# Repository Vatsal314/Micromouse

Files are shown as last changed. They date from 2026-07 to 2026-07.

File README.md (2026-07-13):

# MicroMouse: Autonomous Maze-Solving Robot

An autonomous, self-navigating maze-solving robot designed to map, compute, and solve a grid using the Flood Fill algorithm. The system features a custom-designed PCB to streamline power and sensing, coupled with real-time sensor feedback over standard serial protocols.  

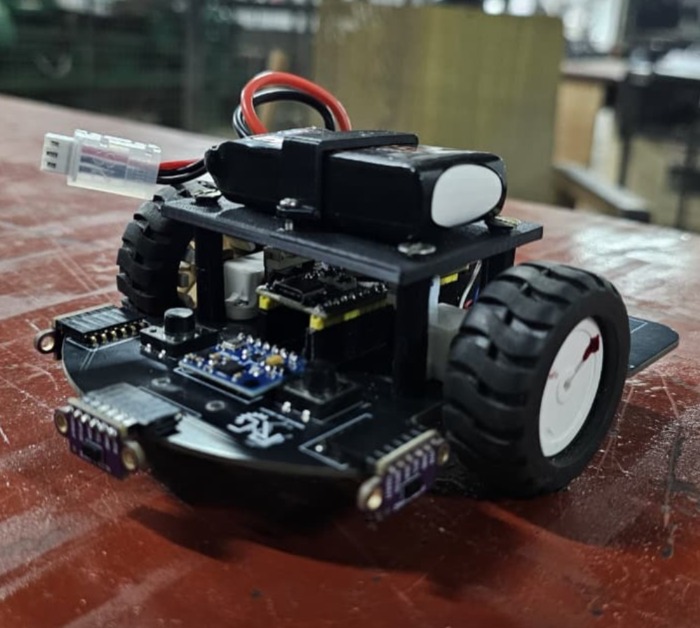
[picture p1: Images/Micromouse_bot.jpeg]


## Tech Stack & Hardware Components
- Microcontroller: STM32F411CEU6 "Black Pill" (ARM Cortex-M4)
- Core Algorithm: Flood Fill (Maze mapping, cell weight updates, and path optimization)
- Sensing & Telemetry: 
  - VL53L0X Time-of-Flight (ToF) sensors for precise distance/wall detection
  - MPU6050 Gyroscope/Accelerometer for straight-line stabilization and precise turns
- Actuation & Control: 
  - 12V 1000RPM N20 Encoder Motors for closed-loop speed control
  - TB6612FNG Dual Motor Driver
- Power Management: 11.1V LiPo battery pack with onboard regulation for logic and motor rails
- Design Tools: KiCad (Schematics & PCB Layout)

## Firmware & Logic Implementation
- Maze Solving: Implements a dynamic Flood Fill matrix routine that updates cell values on the fly as the mouse discovers walls.
- Hardware Integration: Configured SPI/I2C buses to communicate with peripheral sensors and motor drivers, ensuring low-latency feedback loops for precise alignment.

## Hardware Architecture & PCB Design
To minimize structural footprint and eliminate complex wiring failure points, a custom multi-layer PCB was fabricated.
- Power Management: Dedicated onboard regulation filtering out 12V motor noise from the sensitive 3.3V STM32 logic lines.
- Sensor Alignment: Precise angled placement for the VL53L0X ToF sensors to map front and side clearances accurately.

## Maze Description
The robot was tested and validated in a physical maze environment configured with the following specifications:
- Dimensions and Grid: A modular grid layout featuring distinct pathways, vertical wall dividers, and an enclosed central target zone.
- Physical Construction: Built using white foam board panels for the structural walls and a gridded base layer featuring blue alignment markings to delineate cell thresholds.
- Core Objective: The robot starts from the outer perimeter and relies on real-time sensory feedback to dynamically map cell paths, track orientation changes, and navigate toward the centralized goal area.

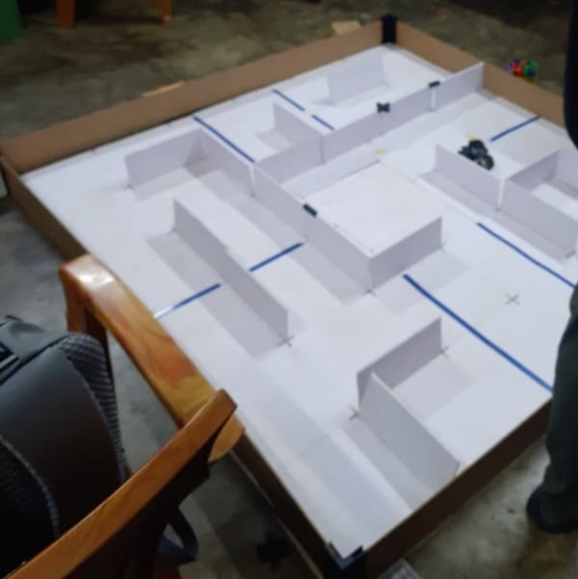
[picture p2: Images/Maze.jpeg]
- 

## Algorithm & Firmware Implementation

The robot utilizes a dynamic Flood Fill algorithm optimized for real-time maze-mapping, tracking orientation updates, path optimization, and execute routines.

### 1. Maze Initialization (Flood Fill Array)
- **Manhattan Distance Matrix:** At startup, the `initFloodfill` routine populates the `arena_map` grid using Manhattan distance bounds calculated relative to the target cell coordinate `(0, length - 1)`. Every cell is given an initial cost matrix weight indicating its theoretical steps away from the destination.
- **Perimeter Boundary Flagging:** The `initWalls` function instantiates the initial maze boundary configuration, defaulting the grid's outer boundary elements to closed parameters.

### 2. Sensor Polling & Real-Time Mapping
- **Dynamic Wall Updating:** During runtime execution loop, the robot polls data from the left, right, and center VL53L0X Time-of-Flight (ToF) sensors. If an obstacle distance drops below `detectDist` (180 mm), the corresponding coordinate index within the global `wall_data` matrix is permanently flagged (`= 1`).
- **Orientation-Aware Bitmasking:** The code tracks the absolute heading (`facing` variable mapping to 0: West, 1: North, 2: East, 3: South). Relative ToF configurations (Left, Front, Right) are translated into absolute compass coordinates to ensure accurate wall updates as the orientation shifts.

### 3. Queue-Driven Map Restructuring (`rearrange_map`)
- **Dead-End Discovery:** If the robot discovers new walls that make its current cell value equal to or lower than all accessible adjacent neighbors, the `rearrange_map` routine initiates.
- **BFS Flood Refresh:** The cell coordinate is pushed onto a custom `Queue` structure. The program continuously pops elements from the queue, calculating the minimum accessible neighbor via `minimum_value_accessible_neighbors`. The cell value is updated dynamically to `smallest_neighbor_value + 1`, and all unblocked adjacent neighbors are placed into the queue to recursively refresh the local routing map.

### 4. Navigation & Path Optimization
- **Compass to Action Translation:** The system determines optimal cell transitions through the `direction_wrt_bot` routine. It converts required compass steps into actual motion commands (`moveForward`, `TurnLeft`, `TurnRight`, `Turn180`).
- **Stack-Based Path Reduction:** As the mouse explores the maze, it tracks steps sequentially inside `path_taken`. Dead ends or backtracks are parsed by `reduceDirections`, which processes the path string through a custom stack interface to discard inverse direction pairings (e.g., North-South or East-West cancellations). This converts the discovery track into a clean tracking coordinate sequence saved into `short_path`.

### 5. Acceleration-Optimized Final Run (`final_run`)
- After mapping out the optimal trajectory, the system executes a localized final straightaway acceleration routine via `final_run`. 
- Instead of stopping at every single node intersection, the algorithm aggregates sequential straight moves (`steps++`). If sequential cells follow a uniform direction, it executes long-distance acceleration (`moveForward(steps * steplength * 0.9)`) coupled with tuned PD constants (`KP_WALL`, `KD_WALL`, `KP_YAW`), leveraging the N20 encoders for high-speed transit.

## Hardware Design & PCB Layout

### Schematic Capture
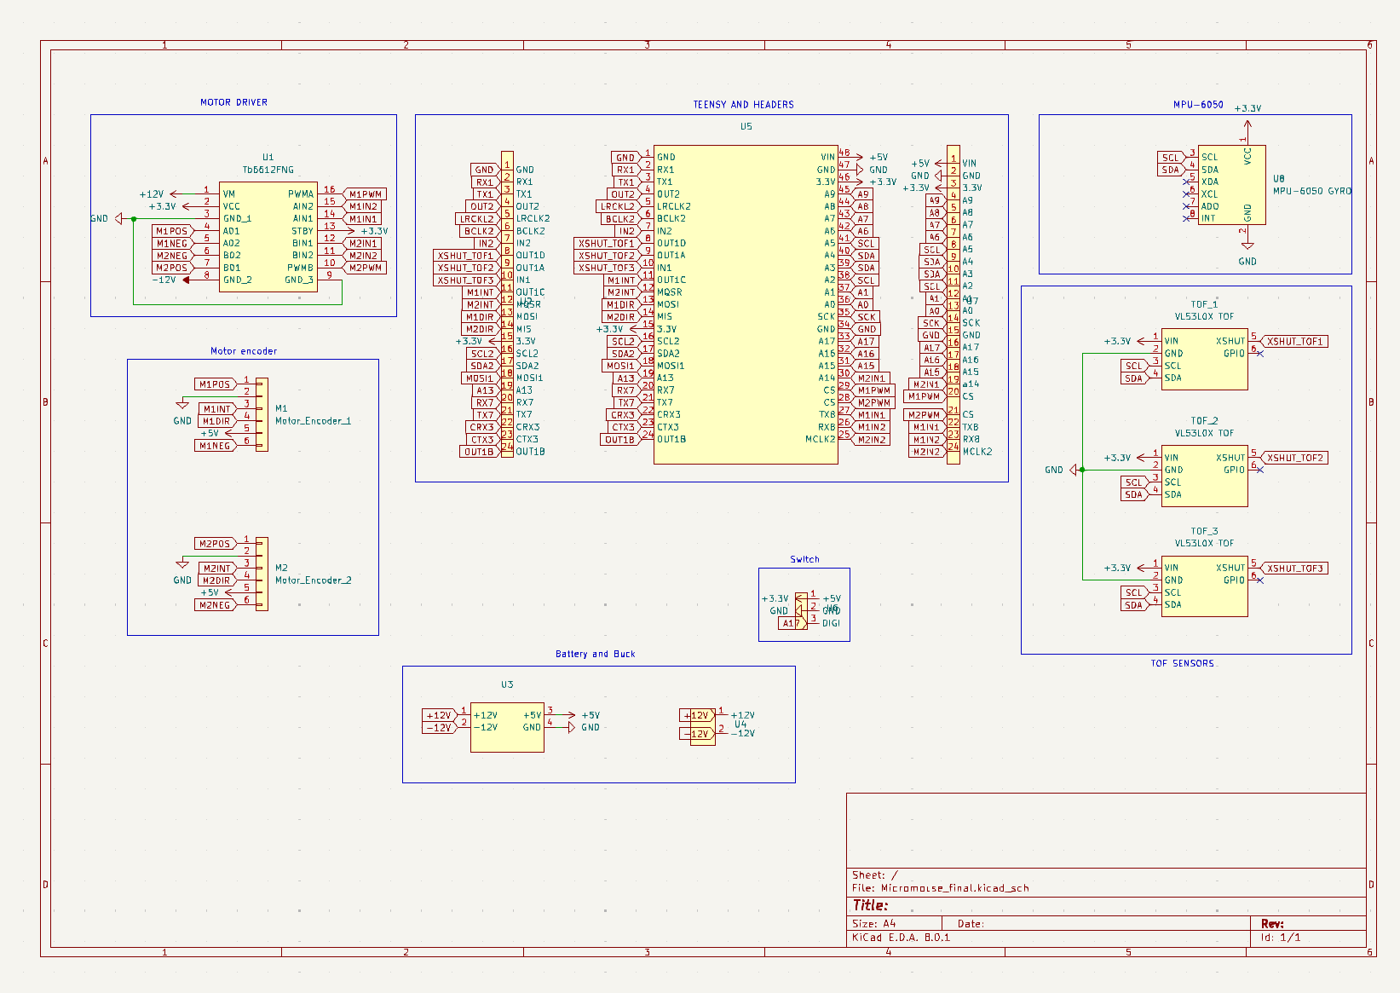
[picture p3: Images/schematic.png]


### PCB Layout & Routing
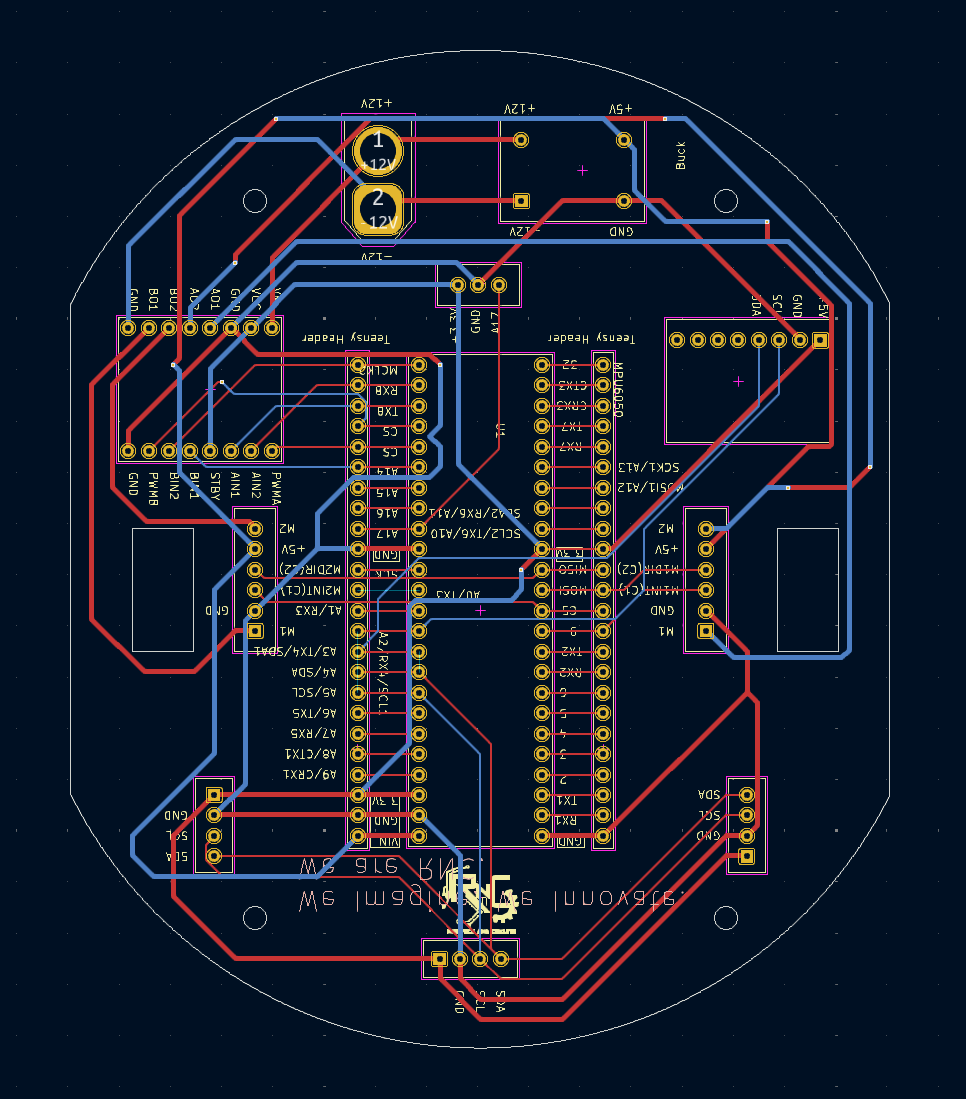
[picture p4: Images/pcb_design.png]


> **Note on Hardware Evolution:** This custom multi-layer PCB was originally architected and routed around a Teensy 4.1 MCU footprint. The subsequent physical implementation and final firmware integration were ported to the STM32F411CEU6 "Black Pill" microcontroller to align with specific processing, layout, and peripheral subsystem constraints.

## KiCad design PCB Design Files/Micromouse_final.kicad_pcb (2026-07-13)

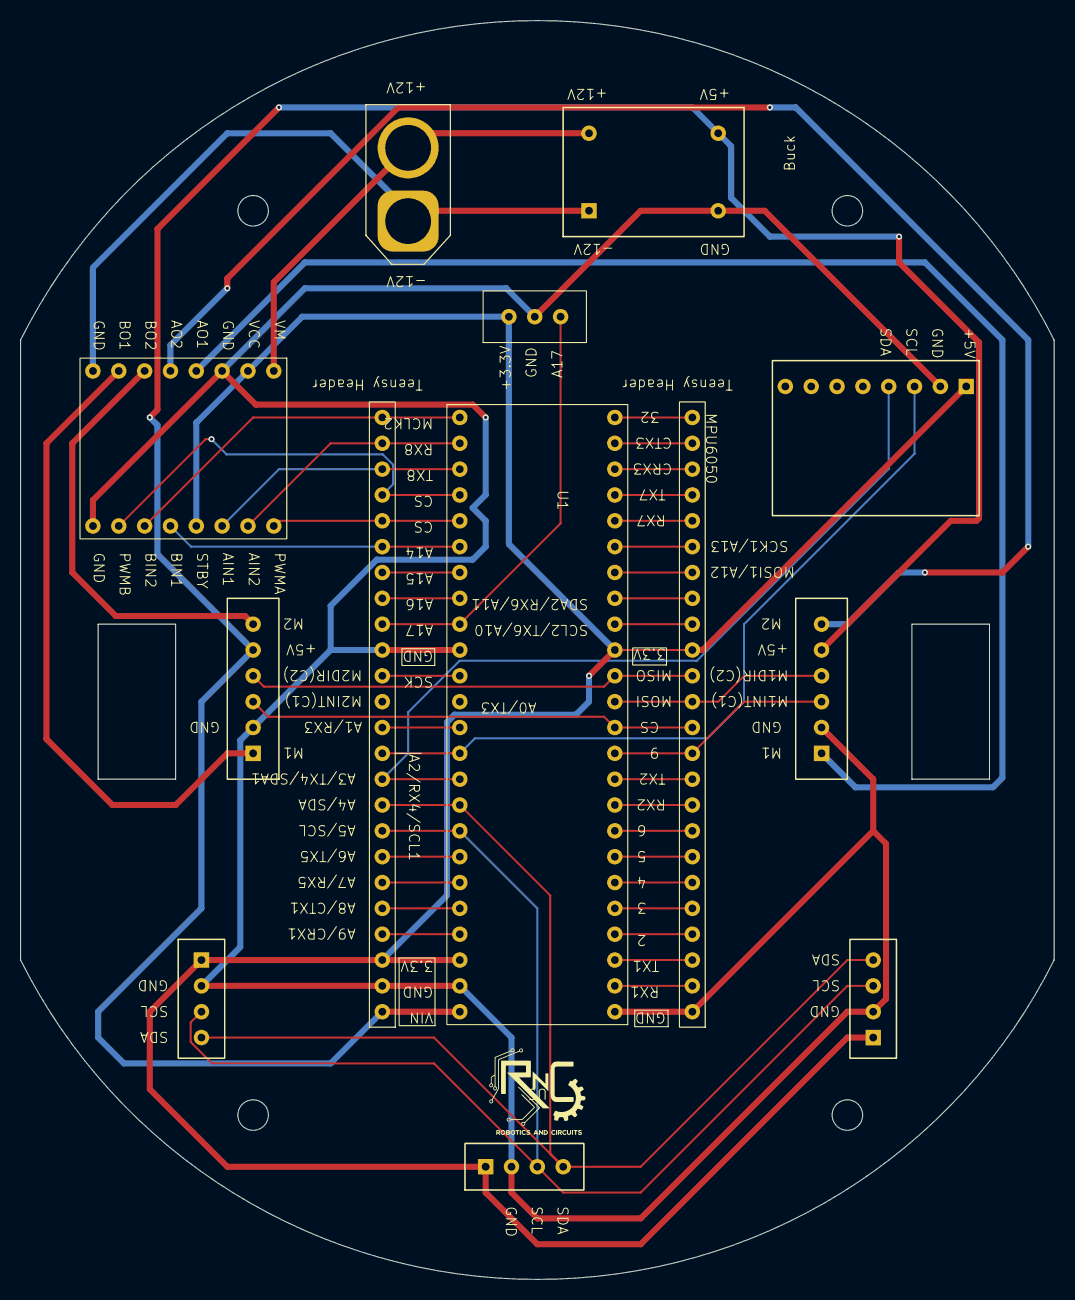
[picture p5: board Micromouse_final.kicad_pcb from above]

Board: 2 copper layers, 101.6 x 123.8 mm, 13 parts (0 on the bottom side), 49 nets.

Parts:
M1: Motor_Encoder_1; Encoder
M2: Motor_Encoder_2; Encoder
TOF_1, TOF_2, TOF_3: VL53L0X TOF; TOF sensor
U1: Tb6612FNG; TB6612FNG
U2, U7: Teensy headers
U3: BUCK
U4: AMASS_XT60-F_1x02_P7.20mm_Vertical
U5: Teensy_4.1
U6: SPDT_micromouse
U8: MPU-6050 GYRO; MPU6050

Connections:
+3.3V: TOF_1.1 (VIN), TOF_2.1 (VIN), TOF_3.1 (VIN), U1.2 (VCC), U1.13 (STBY), U2.15 (3.3V), U5.15 (3.3V), U5.46 (3.3V), U6.1 (+5V), U7.3 (3.3V), U8.1 (VCC)
+5V: M1.5, M2.5, U3.3 (+5V), U5.48 (VIN), U7.1 (VIN)
+12V: U1.1 (VM), U3.1 (+12V), U4.1 (+12V)
-12V: U1.8 (GND_2), U3.2 (-12V), U4.2 (-12V)
A0: U5.36 (A0), U7.13 (A0)
A1: U5.37 (A1), U7.12 (A1)
A6: U5.42 (A6), U7.7 (A6)
A7: U5.43 (A7), U7.6 (A7)
A8: U5.44 (A8), U7.5 (A8)
A9: U5.45 (A9), U7.4 (A9)
A13: U2.19 (A13), U5.19 (A13)
A15: U5.31 (A15), U7.18 (A15)
A16: U5.32 (A16), U7.17 (A16)
A17: U5.33 (A17), U6.3 (DIGI), U7.16 (A17)
BCLK2: U2.6 (BCLK2), U5.6 (BCLK2)
CRX3: U2.22 (CRX3), U5.22 (CRX3)
CTX3: U2.23 (CTX3), U5.23 (CTX3)
GND: M1.2, M2.2, TOF_1.2 (GND), TOF_2.2 (GND), TOF_3.2 (GND), U1.3 (GND_1), U1.9 (GND_3), U2.1 (GND), U3.4 (GND), U5.1 (GND), U5.34 (GND), U5.47 (GND), U6.2 (GND), U7.2 (GND), U7.15 (GND), U8.2 (GND)
IN2: U2.7 (IN2), U5.7 (IN2)
LRCKL2: U2.5 (LRCLK2), U5.5 (LRCLK2)
M1DIR: M1.4, U2.13 (MOSI), U5.13 (MOSI)
M1IN1: U1.14 (AIN1), U5.27 (TX8), U7.22 (TX8)
M1IN2: U1.15 (AIN2), U5.26 (RX8), U7.23 (RX8)
M1INT: M1.3, U2.11 (OUT1C), U5.11 (OUT1C)
M1NEG: M1.6, U1.5 (A02)
M1POS: M1.1, U1.4 (A01)
M1PWM: U1.16 (PWMA), U5.29 (CS), U7.20 (CS)
M2DIR: M2.4, U2.14 (MIS), U5.14 (MIS)
M2IN1: U1.12 (BIN1), U5.30 (A14), U7.19 (a14)
M2IN2: U1.11 (BIN2), U5.25 (MCLK2), U7.24 (MCLK2)
M2INT: M2.3, U2.12 (MQSR), U5.12 (MQSR)
M2NEG: M2.6, U1.6 (B02)
M2POS: M2.1, U1.7 (B01)
M2PWM: U1.10 (PWMB), U5.28 (CS), U7.21 (CS)
MOSI1: U2.18 (MOSI1), U5.18 (MOSI1)
OUT1B: U2.24 (OUT1B), U5.24 (OUT1B)
OUT2: U2.4 (OUT2), U5.4 (OUT2)
RX1: U2.2 (RX1), U5.2 (RX1)
RX7: U2.20 (RX7), U5.20 (RX7)
SCK: U5.35 (SCK), U7.14 (SCK)
SCL: TOF_1.3 (SCL), TOF_2.3 (SCL), TOF_3.3 (SCL), U5.38 (A2), U5.41 (A5), U7.8 (A5), U7.11 (A2), U8.3 (SCL)
SCL2: U2.16 (SCL2), U5.16 (SCL2)
SDA: TOF_1.4 (SDA), TOF_2.4 (SDA), TOF_3.4 (SDA), U5.39 (A3), U5.40 (A4), U7.9 (A4), U7.10 (A3), U8.4 (SDA)
SDA2: U2.17 (SDA2), U5.17 (SDA2)
TX1: U2.3 (TX1), U5.3 (TX1)
TX7: U2.21 (TX7), U5.21 (TX7)
XSHUT_TOF1: U2.8 (OUT1D), U5.8 (OUT1D)
XSHUT_TOF2: U2.9 (OUT1A), U5.9 (OUT1A)
XSHUT_TOF3: U2.10 (IN1), U5.10 (IN1)

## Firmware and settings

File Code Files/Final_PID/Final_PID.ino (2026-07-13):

#include <Wire.h>
#include <VL53L0X.h>
#include <MPU6050_light.h>

#define TOF1_PIN 39
#define TOF2_PIN 40
#define TOF3_PIN 41

VL53L0X sensor1;
VL53L0X sensor2;
VL53L0X sensor3;

int a;
int b;
int c;

MPU6050 mpu(Wire);

unsigned long timer = 0;


void setup()
{
  Serial.begin(9600);
  Serial.println("jdsbaj");

    pinMode(TOF1_PIN, OUTPUT);
    pinMode(TOF2_PIN, OUTPUT);
    pinMode(TOF3_PIN, OUTPUT);

    digitalWrite(TOF1_PIN, LOW);
    digitalWrite(TOF2_PIN, LOW);
    digitalWrite(TOF3_PIN, LOW);
    delay(500);
    Serial.println("jdsbaj");

    Wire.begin();
    digitalWrite(TOF1_PIN, HIGH);
    delay(150);
    sensor1.init(true);
    delay(100);
    sensor1.setAddress((uint8_t)01);

    digitalWrite(TOF2_PIN, HIGH);
    delay(150);
    sensor2.init(true);
    delay(100);
    sensor2.setAddress((uint8_t)02);
    Serial.println("jdsbaj");

    digitalWrite(TOF3_PIN, HIGH);
    delay(150);
    sensor3.init(true);
    delay(100);
    sensor3.setAddress((uint8_t)03);

    Serial.println("addresses set");
    
    sensor1.startContinuous();
    sensor2.startContinuous();
    sensor3.startContinuous();
    Serial.println("jdsbaj");

    // Initialize MPU6050 sensor
    byte status = mpu.begin();
    Serial.print(F("MPU6050 status: "));
    Serial.println(status);
    while (status != 0) {
      Serial.println("Could not connect to MPU6050");
      delay(1000); // Keep trying to connect
      status = mpu.begin();
    }

    Serial.println(F("Calculating offsets, do not move MPU6050"));
    delay(1000);
    mpu.calcOffsets(true, true); // gyro and accelero
    Serial.println("Done!\n");

}

void loop()
{
    a = sensor1.readRangeContinuousMillimeters();
    b = sensor2.readRangeContinuousMillimeters();
    c = sensor3.readRangeContinuousMillimeters();

    // Print sensor readings
    Serial.print("Sensor 1: ");
    Serial.print(a);
    Serial.print(" mm\t");

    Serial.print("Sensor 2: ");
    Serial.print(b);
    Serial.print(" mm\t");

    Serial.print("Sensor 3: ");
    Serial.print(c);
    Serial.print(" mm\n");

     // Read MPU6050 sensor
    mpu.update();
    if ((millis() - timer) > 10) { // print data every 10ms
      Serial.print("X: ");
      Serial.print(mpu.getAngleX());
      Serial.print("\tY: ");
      Serial.print(mpu.getAngleY());
      Serial.print("\tZ: ");
      Serial.println(mpu.getAngleZ());
      timer = millis();
      delay(400);
    }

}

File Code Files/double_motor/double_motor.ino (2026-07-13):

/*
 * The purpose of this code is to count the ouput pulses or
 * the encoder outputs as you rotate the Motor shaft. You can run the
 * same code on the Arduino Uno, Arduino Nano, Arduino Mega, etc.
 */
#define M1_ENC_A 9// pin2 of the Arduino
#define M1_ENC_B 11// pin 3 of the Arduino
// these two pins has the hardware interrupts as well.
#define M2_ENC_A 12 // pin2 of the Arduino
#define M2_ENC_B 14

#define M1_PWM 37
#define M1_in2 34
#define M1_in1 35

#define M2_PWM 36
#define M2_in2 33
#define M2_in1 38

int m1_count_pulses = 0;
int m2_count_pulses = 0;

void setup()
{
  Serial.begin(9600);                // activates the serial communication
  pinMode(M1_ENC_A, INPUT); // sets the Encoder_output_A pin as the input
  pinMode(M1_ENC_B, INPUT); // sets the Encoder_output_B pin as the input
  attachInterrupt(digitalPinToInterrupt(M1_ENC_A), M1_Encoder_Interrupt, RISING);

  pinMode(M2_ENC_A, INPUT); // sets the Encoder_output_A pin as the input
  pinMode(M2_ENC_B, INPUT); // sets the Encoder_output_B pin as the input
  attachInterrupt(digitalPinToInterrupt(M2_ENC_A), M2_Encoder_Interrupt, RISING);

  pinMode(M1_PWM, OUTPUT);
  pinMode(M1_in1, OUTPUT);
  pinMode(M1_in2, OUTPUT);

  pinMode(M2_PWM, OUTPUT);
  pinMode(M2_in1, OUTPUT);
  pinMode(M2_in2, OUTPUT);
}

void loop()
{
  digitalWrite(M1_in1, HIGH);
  digitalWrite(M1_in2, LOW);

  digitalWrite(M2_in1, HIGH);
  digitalWrite(M2_in2, LOW);

  analogWrite(M1_PWM, 255);
  analogWrite(M2_PWM, 255);
  
  Serial.println("Result A: ");
  Serial.println(m1_count_pulses);
  Serial.print("Results B:");
  Serial.println(m2_count_pulses);
  delay(100);
}

void M1_Encoder_Interrupt()
{
  int b = digitalRead(M1_ENC_B);
  if (b > 0)
  {
    m1_count_pulses++;
  }
  else
  {
    m1_count_pulses--;
  }
}
void M2_Encoder_Interrupt()
{
  int c = digitalRead(M2_ENC_B);
  if (c > 0)
  {
    m2_count_pulses++;
  }
  else
  {
    m2_count_pulses--;
  }
}

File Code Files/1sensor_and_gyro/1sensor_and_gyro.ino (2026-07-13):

#include <stdio.h>
#include <string.h>
#include <config.h>
#define MAX 1000
#include <floodfill.h>
#include "data_structures.h"
const float steplength=26.2;
short y_length = length;
char path_taken[length * length];
int path_index = 0;
char path[4000];
Queue queue;

int detectDist=180;



const double KP_WALL = 0.15, KD_WALL = 0.2,KP_YAW =0.1;//final run constants

bool last_was_back = false;
char short_path[4000];
int short_path_index = 0;

int isOpposite(char a, char b) {
  return (a == 'N' && b == 'S') ||
         (a == 'S' && b == 'N') ||
         (a == 'E' && b == 'W') ||
         (a == 'W' && b == 'E');
}

void reduceDirections(const char* input) {
  char stack[MAX];
  int top = -1;

  for (int i = 0; input[i] != '\0'; i++) {
    char dir = input[i];
    if (top >= 0 && isOpposite(stack[top], dir)) {
      top--;  // Cancel out opposite direction
    } else {
      stack[++top] = dir;  // Push direction to stack
    }
  }

  // Print reduced result
  Serial.println("Reduced directions:");
  for (int i = 0; i <= top; i++) {
    Serial.print(stack[i]);
    short_path[i]=stack[i];
  }
  Serial.println();
}
bool dup_arr[length][length][4] ={
    {{1,1,1,0},{1,1,0,0},{0,1,0,1},{0,1,1,0},{1,1,1,0},{1,1,1,0}},
    {{1,0,0,1},{0,0,1,0},{1,1,0,1},{0,0,0,1},{0,0,1,0},{1,0,1,0}},
    {{1,1,1,0},{1,0,1,0},{1,1,0,0},{0,1,0,0},{0,0,1,0},{1,0,1,0}},
    {{1,0,0,0},{0,0,1,1},{1,0,0,1},{0,0,1,1},{1,0,0,0},{0,0,1,1}},
    {{1,0,0,0},{0,1,1,0},{1,1,0,0},{0,1,0,1},{0,0,0,1},{0,1,1,1}},
    {{1,0,1,1},{1,0,0,1},{0,0,0,1},{0,1,0,1},{0,1,0,1},{0,1,1,1}}
    };


bool wall_data[length][length][4];

void initWalls() {
    for (int r = 0; r < length; r++) {
        for (int c = 0; c < length; c++) {
            wall_data[r][c][0] = (c == 0);         // West wall
            wall_data[r][c][1] = (r == 0);  // NORTH wall
            wall_data[r][c][2] = (c == length - 1);  // East wall
            wall_data[r][c][3] = (r= length-1);         // South wall
        }
    }
}


// bool wall_data[length][length][4] ={
//     {{1,1,0,0},{1,1,0,0},{0,1,0,0},{0,1,0,0},{0,1,0,0},{0,1,1,0}},
//     {{1,0,0,0},{0,0,0,0},{0,0,0,0},{0,0,0,0},{0,0,0,0},{0,0,1,0}},
//     {{1,0,0,0},{0,0,0,0},{0,0,0,0},{0,0,0,0},{0,0,0,0},{0,0,1,0}},
//     {{1,0,0,0},{0,0,0,0},{0,0,0,0},{0,0,0,0},{0,0,0,0},{0,0,1,0}},
//     {{1,0,0,0},{0,0,0,0},{0,0,0,0},{0,0,0,0},{0,0,0,0},{0,0,1,0}},
//     {{1,0,0,1},{0,0,0,1},{0,0,0,1},{0,0,0,1},{0,0,0,1},{0,0,1,1}}
//     };

void print_path_taken() {
    Serial.print("\nPath taken by bot: ");
    for (int i = 0; i < path_index; i++) {
        Serial.print(path_taken[i]);
        Serial.print(" ");
    }
    Serial.println();
    reduceDirections(path_taken);
}

void print_short_path() {
    Serial.print("\nshort path: ");
    for (int i = 0; i < short_path_index; i++) {
        Serial.print(short_path[i]);
        Serial.print(" ");
    }
    Serial.println();
}

int* minimum_cost(short arena_map[length][length], short bot_pos[2], int *sortedArray) {
    /*
        returns array with [0,1,2,3] as [l,s,r,b] in ascending order of their weights
        Function verified
    */

    // Getting values of neighbors
    int top, left, bottom, right;

    // If condition is to check for array out of bound condition
    if (bot_pos[0] == 0) { // if bot is at top row
        top = 1000;
    } else {
        top = arena_map[bot_pos[0] - 1][bot_pos[1]];
    }

    if (bot_pos[0] == (length-1)) { // if bot is at bottom row
        bottom = 1000;
    } else {
        bottom = arena_map[bot_pos[0] + 1][bot_pos[1]];
    }

    if (bot_pos[1] == 0) { // if bot is at leftmost column
        left = 1000;
    } else {
        left = arena_map[bot_pos[0]][bot_pos[1] - 1];
    }

    if (bot_pos[1] == (length-1)) { // if bot is at rightmost column
        right = 1000;
    } else {
        right = arena_map[bot_pos[0]][bot_pos[1] + 1];
    }

    int *return_value = (int *)calloc(4, sizeof(int));
    int temp_arr[4]; 

   switch (digitalRead(SWITCH)) {
        case 0:
            return_value[0] = 2; // r
            return_value[1] = 1; // s
            return_value[2] = 0; // l
            return_value[3] = 3; // b

            temp_arr[0] = right;
            temp_arr[1] = top;
            temp_arr[2] = left;
            temp_arr[3] = bottom;
            break;

        case 1:
            return_value[0] = 0; // l
            return_value[1] = 1; // s
            return_value[2] = 2; // r
            return_value[3] = 3; // b

            temp_arr[0] = left;
            temp_arr[1] = top;
            temp_arr[2] = right;
            temp_arr[3] = bottom;
            break;

        default:
            // handle unexpected output
            temp_arr[0] = left;
            temp_arr[1] = top;
            temp_arr[2] = right;
            temp_arr[3] = bottom;
            break;
    }

    int smallest = 0;



    // Sorting array (selection sort)
    for (int i = 0; i < 4; i++) {
        smallest = i;
        for (int j = i + 1; j < 4; j++) {
            if (temp_arr[smallest] > temp_arr[j]) {
                smallest = j;
            }
        }

        // Swap values
        int temp = temp_arr[i];
        temp_arr[i] = temp_arr[smallest];
        temp_arr[smallest] = temp;

        temp = return_value[i];
        return_value[i] = return_value[smallest];
        return_value[smallest] = temp;
    }

    // Copying sorted array to sortedArray
    for (int i = 0; i < 4; i++) {
        sortedArray[i] = temp_arr[i];
    }

    return return_value;
}
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
